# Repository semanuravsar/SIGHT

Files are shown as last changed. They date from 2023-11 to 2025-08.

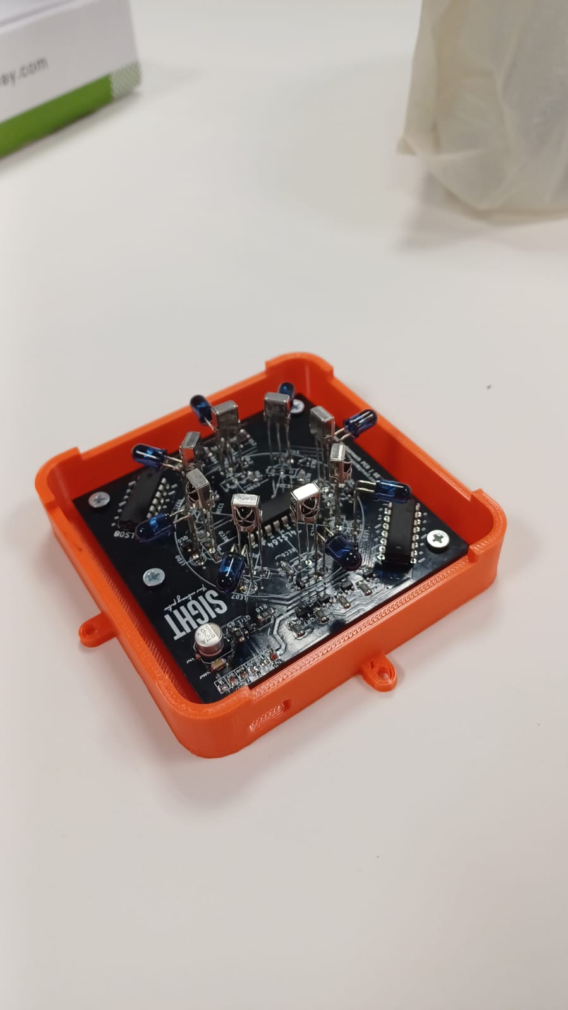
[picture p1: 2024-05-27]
Final Demo Poster/images/com_case_1.jpeg

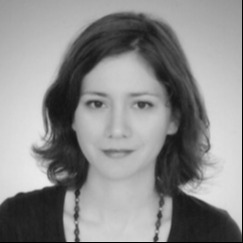
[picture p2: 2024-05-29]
Final Demo Poster/images/elif_photo-modified.jpg

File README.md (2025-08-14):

# SIGHT
A repository for the Ad-Hoc Comm. Project of SIGHT company.

## **Overview**  
This project implements an **autonomous multi-unit robotic system** for searching a **9×9 tiled field** to locate a designated target.  

- Each tile has an **RFID tag** encoding its coordinates and whether it contains the target.  
- The system includes multiple **Mobile Units (MUs)** and one **Base Unit (BU)**.  
- **MUs**: Search assigned regions, detect targets, share findings **with each other** via narrow-angle communication links, and converge when a target is found.  
- **BU**: Broadcasts target location to all units once detected.  

**Search Strategy – Predetermined Area Assignment**  
- The field is divided into three **3×9 regions**, one per MU.  
- Units scan their assigned regions independently.  
- Upon detecting the target, the discovering MU shares its location, prompting all units to converge.  

## **Video Demonstration**  
Watch the project in action here:  
- [Project Video](https://www.youtube.com/watch?v=MVDLl5eAIYU)  

## Poster
- [Project Poster (PDF)](Final%20Demo%20Poster/Sight_poster_30_05_2024_05-17.pdf)

## Final Report
- [Project Final Report (PDF)](reports/Final-Report.pdf)

---

## **Subsystems**  

### **1. Communication Unit**  
- **Hardware:** 8 × IR transmitter/receiver pairs at 45° spacing.  
- **Operation:** Sequentially activates pairs to determine direction of incoming pings.  
- **Communication Type:** **Narrow-angle IR**, enabling targeted, directional data exchange between MUs and reducing interference.  
- **Protocol:**  
  - Custom **ping/ack** messages: 3-byte payload + 1-byte CRC.  
  - Payload includes: next position, unit ID, search state, target position.  
  - CRC ensures data integrity.  
- **Search States:** 6 defined (moving to area, searching, target not found, target found, moving to target, target reached). Ack = state + 9.  
- **Performance:** ≥95% success within ±22.5° at 0.5 m; ≥90% at 1 m; stable for 4-, 8-, and 12-byte packets at 1 m.  

### **2. Decision Unit**  
- Implements the **Predetermined Area Assignment** algorithm.  
- Maintains latest states/positions of other MUs to prevent collisions.  
- Assigns movement priorities based on defined search states.  

### **3. Sensing Unit**  
- **Method:** RFID-based localization.  
- **Hardware:**  
  - Passive **13.56 MHz RFID tags** on each tile.  
  - Target tiles: coordinate values incremented by +9.  
  - Each MU has an RFID reader mounted underneath.  
- **Operation:**  
  - Reads tags in milliseconds while moving at 10 cm/s (no stop needed).  
  - On read, MU pauses 500 ms to process.  

### **4. Motion Unit**  
- **Submodules:** Mechanical, driving, and feedback.  
- **Driving:**  
  - **L293N H-bridge** motor driver.  
  - Direction via IN pins, speed via PWM on EN pins.  
  - Gradual PWM ramp to avoid surges and resets.  
- **Feedback & Navigation:**  
  - Line follower on black-on-white grid.  
  - Ensures accurate RFID positioning.  
- **Recovery:** Back-and-forth routine if tag read is missed.  

### **5. Power Unit**  
- **Consumption:** ~4.6 W average (motors ~3.45 W).  
- **Supply:** Two 18650 Li-ion cells in series (7.4 V, 3.5 A peak).  
- **Runtime:** >5 hours at worst-case 7.5 W.  
- **Regulation:** Linear 5 V; remove batteries for charging.  

## **System Workflow**  
1. MUs start at the base and move toward their assigned regions.  
2. Each MU scans tiles, reading RFID tags to determine position and target status.  
3. MUs exchange status and target information with each other via **narrow-angle IR communication**.  
4. If a target is detected, the discovering MU broadcasts location, and all MUs converge on it.  

---

## Authors
Erdem Canaz, Semanur Avşar, Humeyra Bodur, Özge Deniz Ateş, Berfin Kökmen, Yiğit Sayar

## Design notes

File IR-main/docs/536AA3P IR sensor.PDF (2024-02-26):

Part Number : 536AA3P, TSOP1136, TSOP1736

Manufacturers : Vishay

Function : IR Receiver Module

Image :

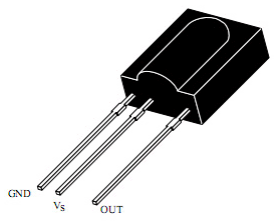
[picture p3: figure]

Description
The 536AA3P is miniaturized receivers for infrared remote control systems. A PIN diode and a preamplifier are assembled on a lead frame, the epoxy package acts as an IR filter.

Features

### 1. Very low supply current 2. Photo detector and preamplifier in one package 3. Internal filter for PCM frequency 4. Improved shielding against EMI

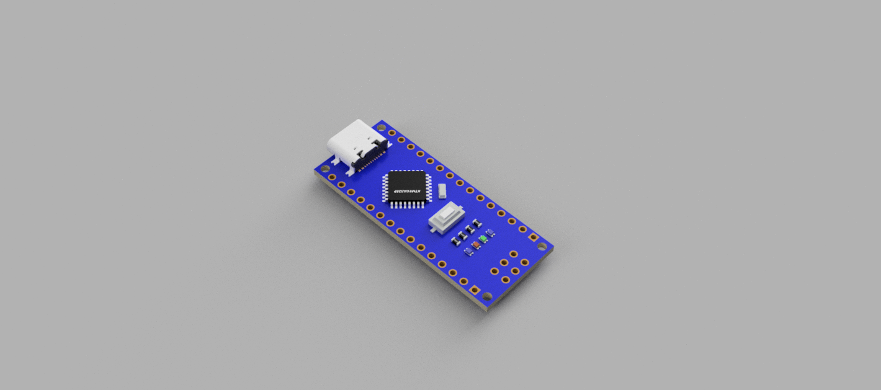
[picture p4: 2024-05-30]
Final Demo Poster/images/Arduino Nano Alibaba v1.png

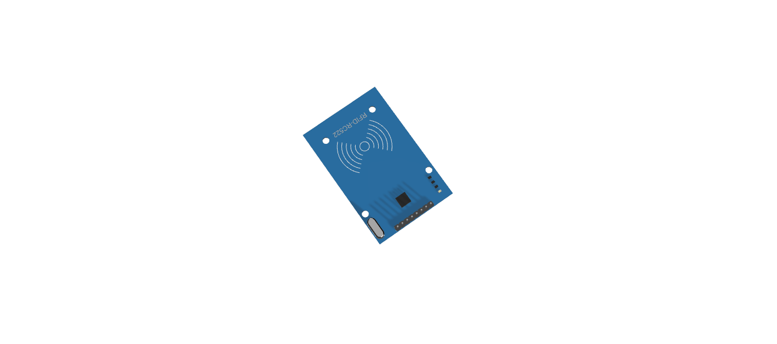
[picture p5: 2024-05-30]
Final Demo Poster/images/RFID.png

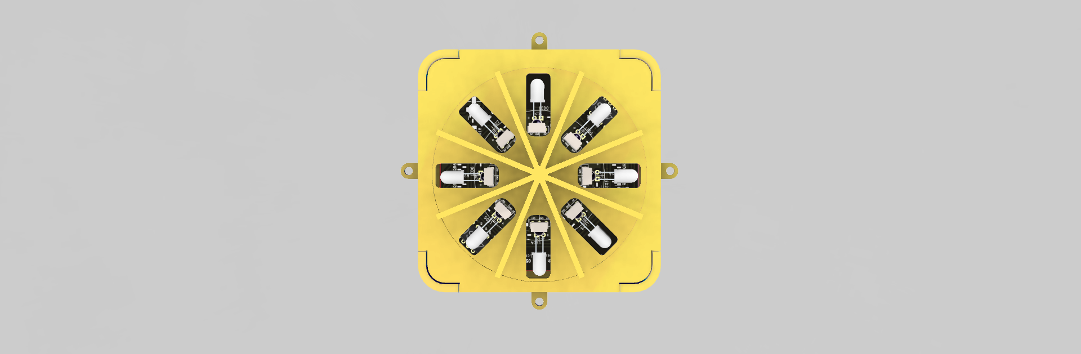
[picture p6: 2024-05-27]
Final Demo Poster/images/com_3D_top.png

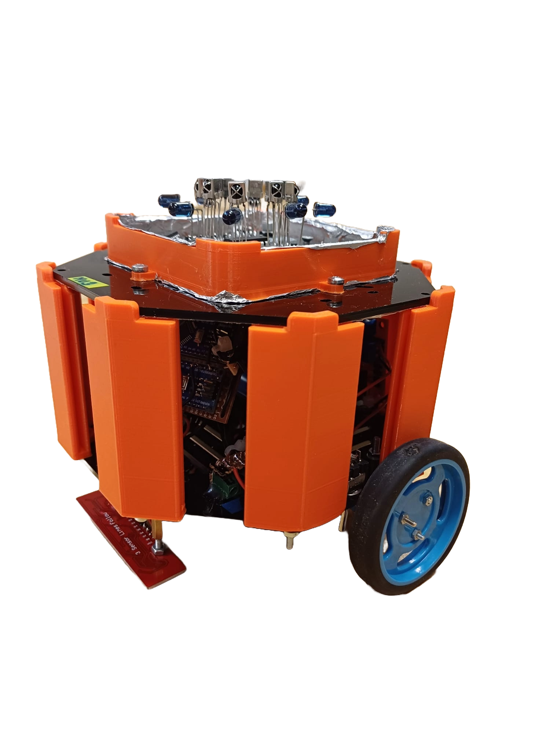
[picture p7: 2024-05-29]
Final Demo Poster/images/mu_nobg.png

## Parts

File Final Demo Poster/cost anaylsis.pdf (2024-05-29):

Microcontrollers | $40
Motor drivers, motors and wheels | $36
Batteries | $26.5
Line follower and RFID reader sensors | $12
RFID Tags | $14.5
IR transmitters, receivers and PCB | $36
Chassis | $10
Grid | $66
Circuit components (Breadboard, cables, resistors) | $10
Total Cost | $251

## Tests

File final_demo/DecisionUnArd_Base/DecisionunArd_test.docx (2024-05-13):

// The values info matrix represent the following;

// mu1 is here == 1

// mu2 is here == 2

// mu3 is here == 3

// BU is here == 4

// This tile is scanned == 5

// This tile has not been scanned == 0

// The target is there == 6

// mu is planning to go here == 7

// obtacle here == 8

#include "DecisionUnArd_header.h";

// Define positions

Position buPosition = {5, 5};

Position currentPosition = {6, 1};

// Position unknownTargetPosition = {1, 9};

Position targetPosition = {7,9};

// Define obstacles

Position obstacles[MAX_OBSTACLES];

int obstacleCount = 2;

int buLink = 0;

// Define mu_info_matrix

int mu_info_matrix[GRID_SIZE][GRID_SIZE] = {

{0, 0, 0, 0, 0, 0, 0, 0, 0},

{0, 0, 0, 0, 8, 8, 0, 0, 0},

{0, 0, 0, 0, 0, 0, 0, 0, 0},

{7, 7, 7, 7, 7, 7, 7, 7, 7},

{7, 7, 7, 7, 4, 7, 7, 7, 7},

{7, 7, 7, 7, 7, 7, 7, 7, 7},

{7, 7, 7, 7, 7, 7, 7, 7, 7},

{7, 7, 7, 7, 7, 7, 7, 7, 7},

{7, 7, 7, 7, 7, 7, 7, 7, 7}

};

// Set state to MOVING_TO_SEARCH_AREA

int state = MOVING_TO_SEARCH_AREA;

// Test function

// Test function

void test_move_decider_MU1() {

// Call move_decider_MU1

Position nextMoveResult = move_decider_MU1(buPosition, currentPosition, targetPosition, obstacles, obstacleCount, mu_info_matrix, state, buLink);

if(nextMoveResult.x != 0 || nextMoveResult.y != 0){

// Checking first the BU connecition

if(((buPosition.x-currentPosition.x)^2 + (buPosition.y-currentPosition.y)^2)<10){

buLink = 1;

Serial.println("**************BU LINK IS ESTABLISHED");

}

else{

buLink = 0;

Serial.println("**************NO LINK WITH THE BU");

}

// Updating the info matrix

if(currentPosition.x == targetPosition.x && currentPosition.y == targetPosition.y){

Serial.println("Target has been found.");

state = TARGET_FOUND;

// Updating the info matrix

mu_info_matrix[currentPosition.x-1][currentPosition.y - 1] = 6;

}

else{

mu_info_matrix[currentPosition.x-1][currentPosition.y - 1] = 5;

}

currentPosition.x = currentPosition.x + nextMoveResult.x;

currentPosition.y = currentPosition.y + nextMoveResult.y;

mu_info_matrix[currentPosition.x-1][currentPosition.y - 1] = 1;

// If our state is searching and we have not more unscaenned tiles left

if(state == CURRENTLY_SEARCHING && !unscannedTileLeft(mu_info_matrix)){

state = TARGET_NOT_FOUND;

}

}

// Output the result

Serial.print("Move made: (");

Serial.print(nextMoveResult.x);

Serial.print(", ");

Serial.print(nextMoveResult.y);

Serial.println(")");

// Current State

Serial.print("Current State: ");

Serial.println(state);

// Current Position

// Output the result

Serial.print("Current Position: (");

Serial.print(currentPosition.x);

Serial.print(", ");

Serial.print(currentPosition.y);

Serial.println(")");

// Print out the mu_info_matrix

Serial.println("mu_info_matrix:");

for (int i = 0; i < GRID_SIZE; i++) {

for (int j = 0; j < GRID_SIZE; j++) {

Serial.print(mu_info_matrix[i][j]);

Serial.print("\t");

}

Serial.println();

}

}

// Setup function

void setup() {

// Initialize serial communication

Serial.begin(9600);

obstacles[0].x = 2;

obstacles[0].y = 5;

obstacles[1].x = 2;

obstacles[1].y = 6;

// Test the move_decider_MU1 function

test_move_decider_MU1();

test_move_decider_MU1();

test_move_decider_MU1();

test_move_decider_MU1();

test_move_decider_MU1();

test_move_decider_MU1();

test_move_decider_MU1();

test_move_decider_MU1();

test_move_decider_MU1();

test_move_decider_MU1();

test_move_decider_MU1();

test_move_decider_MU1();

test_move_decider_MU1();

test_move_decider_MU1();

test_move_decider_MU1();

test_move_decider_MU1();

test_move_decider_MU1();

test_move_decider_MU1();

test_move_decider_MU1();

test_move_decider_MU1();

test_move_decider_MU1();

test_move_decider_MU1();

test_move_decider_MU1();

test_move_decider_MU1();

test_move_decider_MU1();

test_move_decider_MU1();

test_move_decider_MU1();

test_move_decider_MU1();

test_move_decider_MU1();

test_move_decider_MU1();

test_move_decider_MU1();

test_move_decider_MU1();

test_move_decider_MU1();

test_move_decider_MU1();

test_move_decider_MU1();

test_move_decider_MU1();

test_move_decider_MU1();

// Gets in the perimiter of the BU

test_move_decider_MU1();

test_move_decider_MU1();

test_move_decider_MU1();

test_move_decider_MU1();

Serial.println(buLink);

test_move_decider_MU1();

test_move_decider_MU1();

test_move_decider_MU1();

// Receives the info on the target from another MU

state = MOVING_TO_TARGET;

test_move_decider_MU1();

test_move_decider_MU1();

test_move_decider_MU1();

test_move_decider_MU1();

test_move_decider_MU1();

test_move_decider_MU1();

test_move_decider_MU1();

test_move_decider_MU1();

test_move_decider_MU1();

test_move_decider_MU1();

}

// Loop function

void loop() {

// Nothing to do here since we're testing in setup()

}

// Function to check if all elements in the matrix are non-zero

bool unscannedTileLeft(const int matrix[GRID_SIZE][GRID_SIZE]) {

for (int i = 0; i < GRID_SIZE; i++) {

for (int j = 0; j < GRID_SIZE; j++) {

if (matrix[i][j] == 0) {

return true;

}

}

}

return false;

}

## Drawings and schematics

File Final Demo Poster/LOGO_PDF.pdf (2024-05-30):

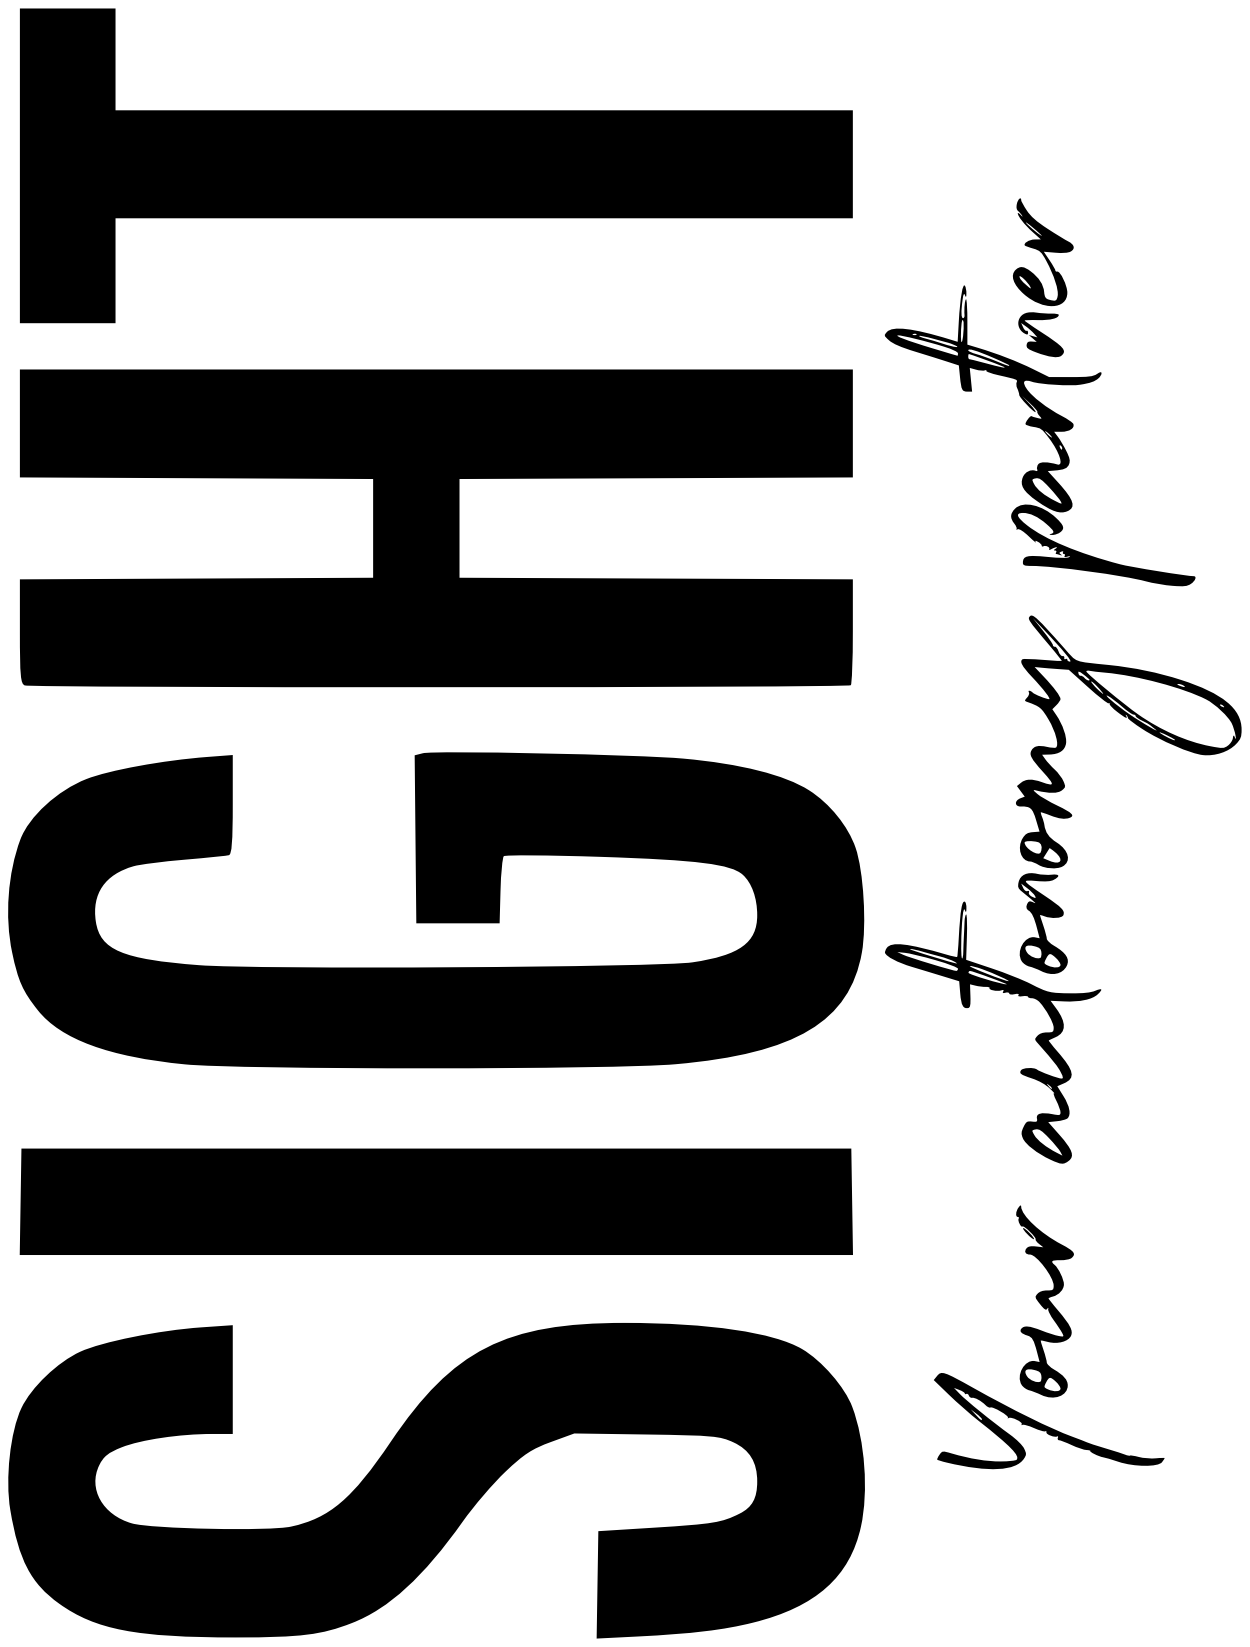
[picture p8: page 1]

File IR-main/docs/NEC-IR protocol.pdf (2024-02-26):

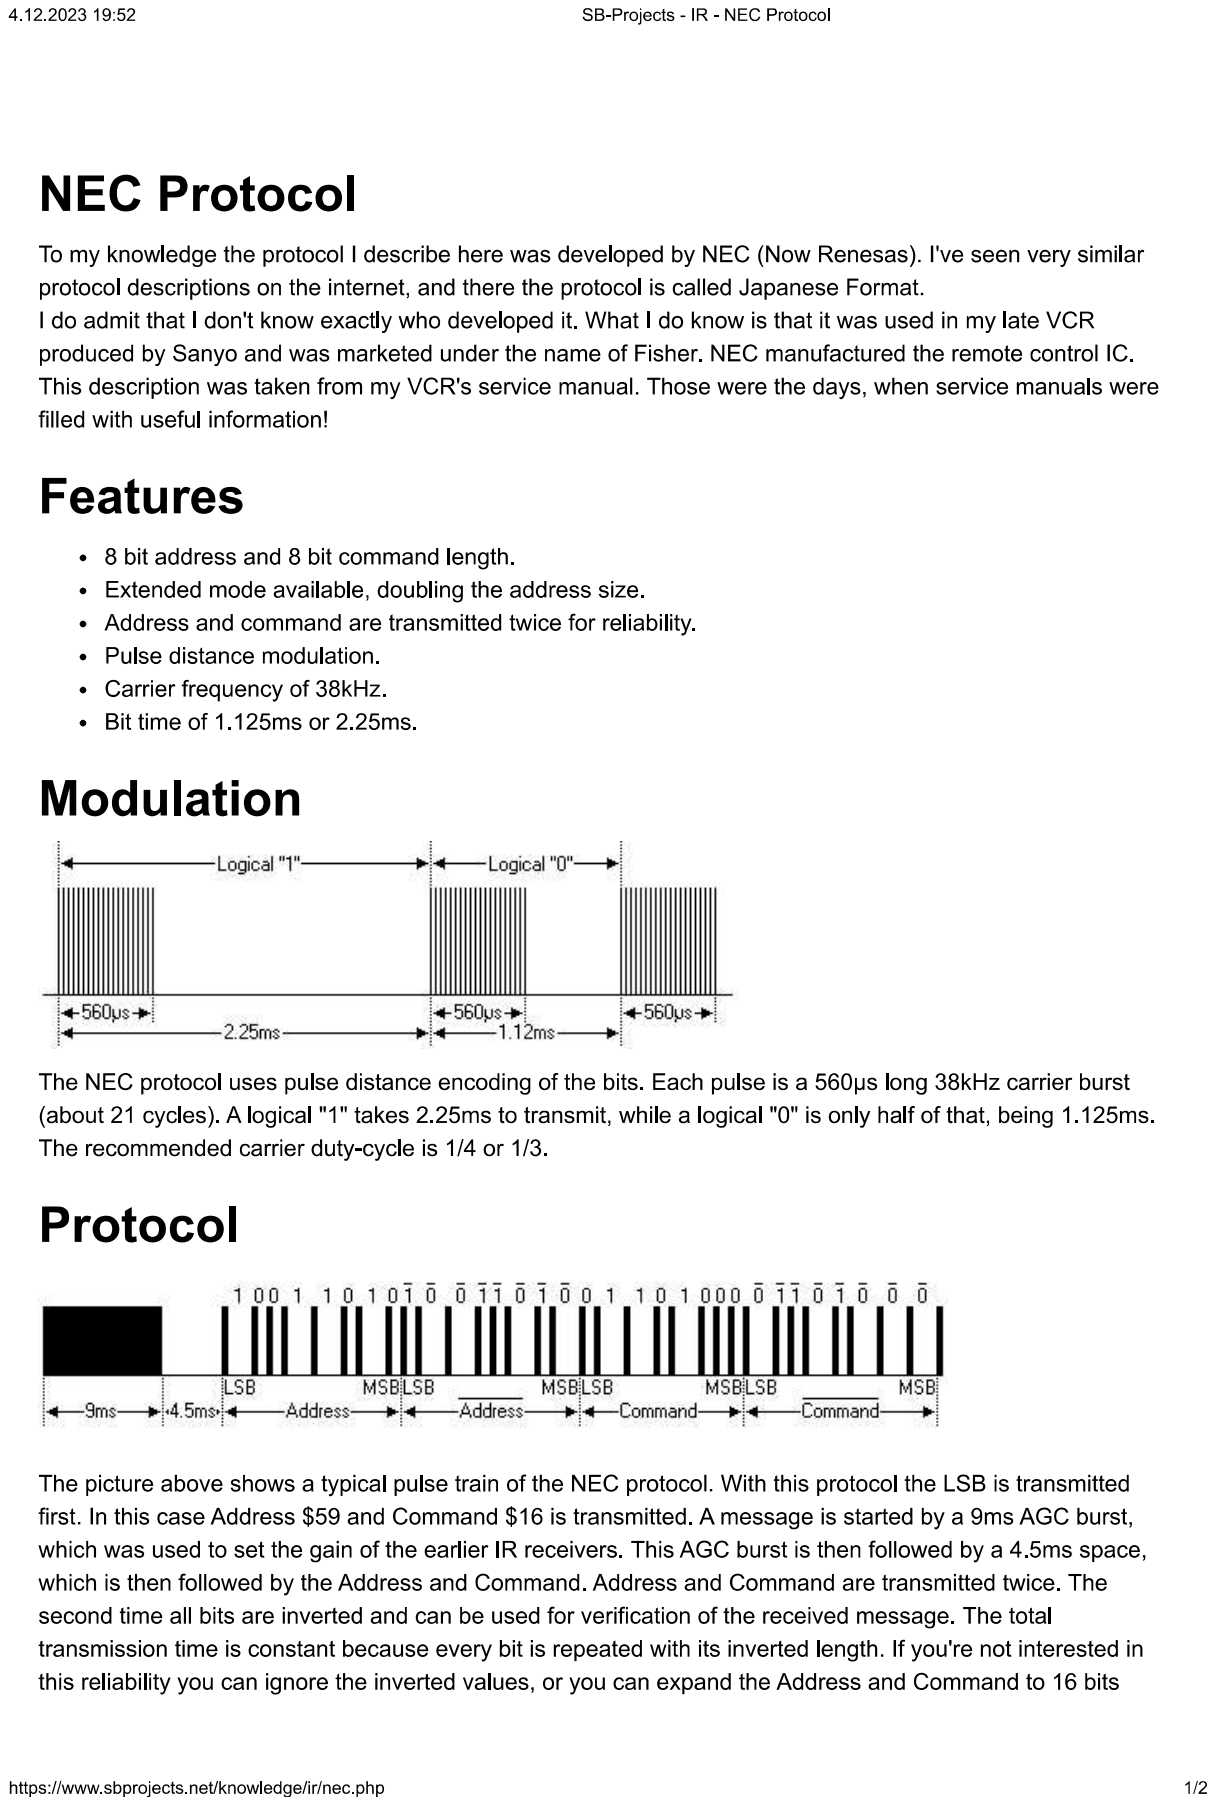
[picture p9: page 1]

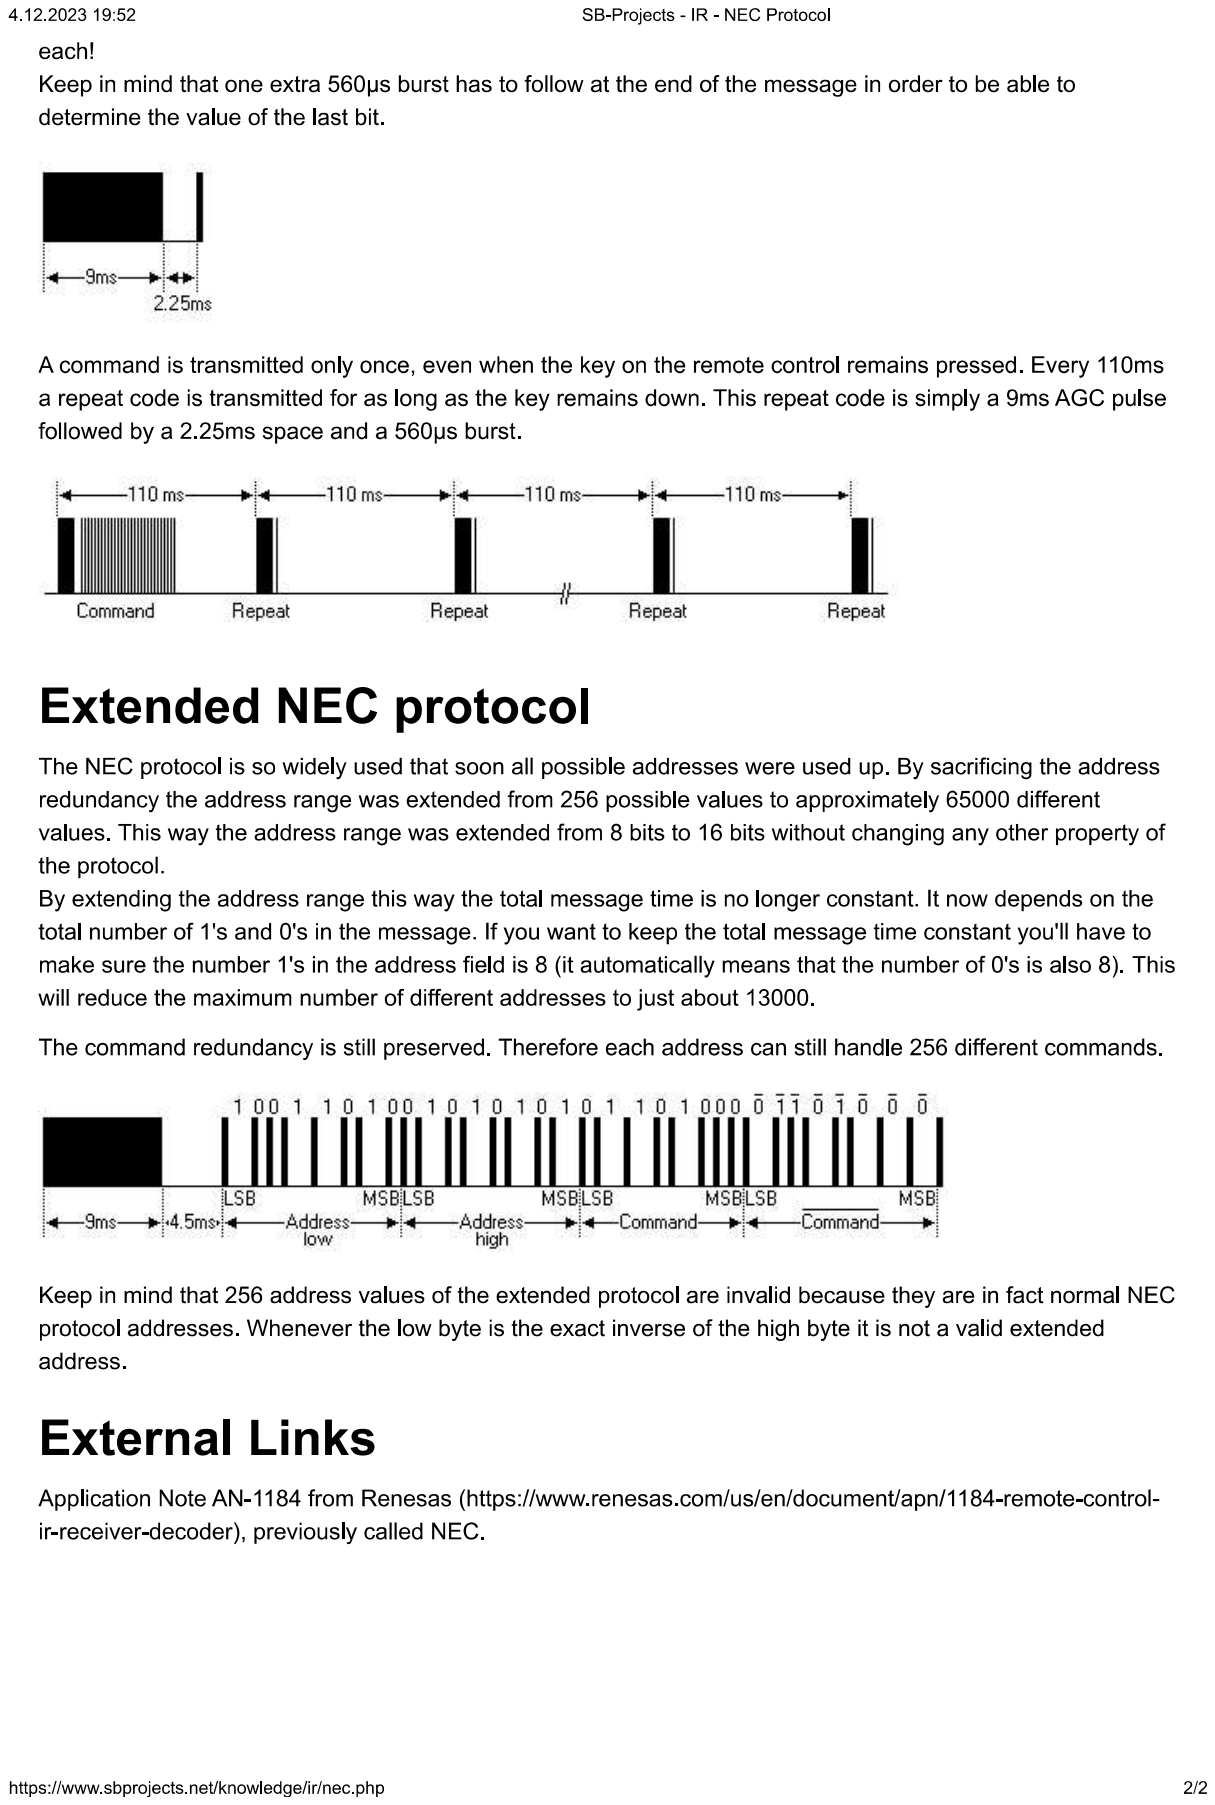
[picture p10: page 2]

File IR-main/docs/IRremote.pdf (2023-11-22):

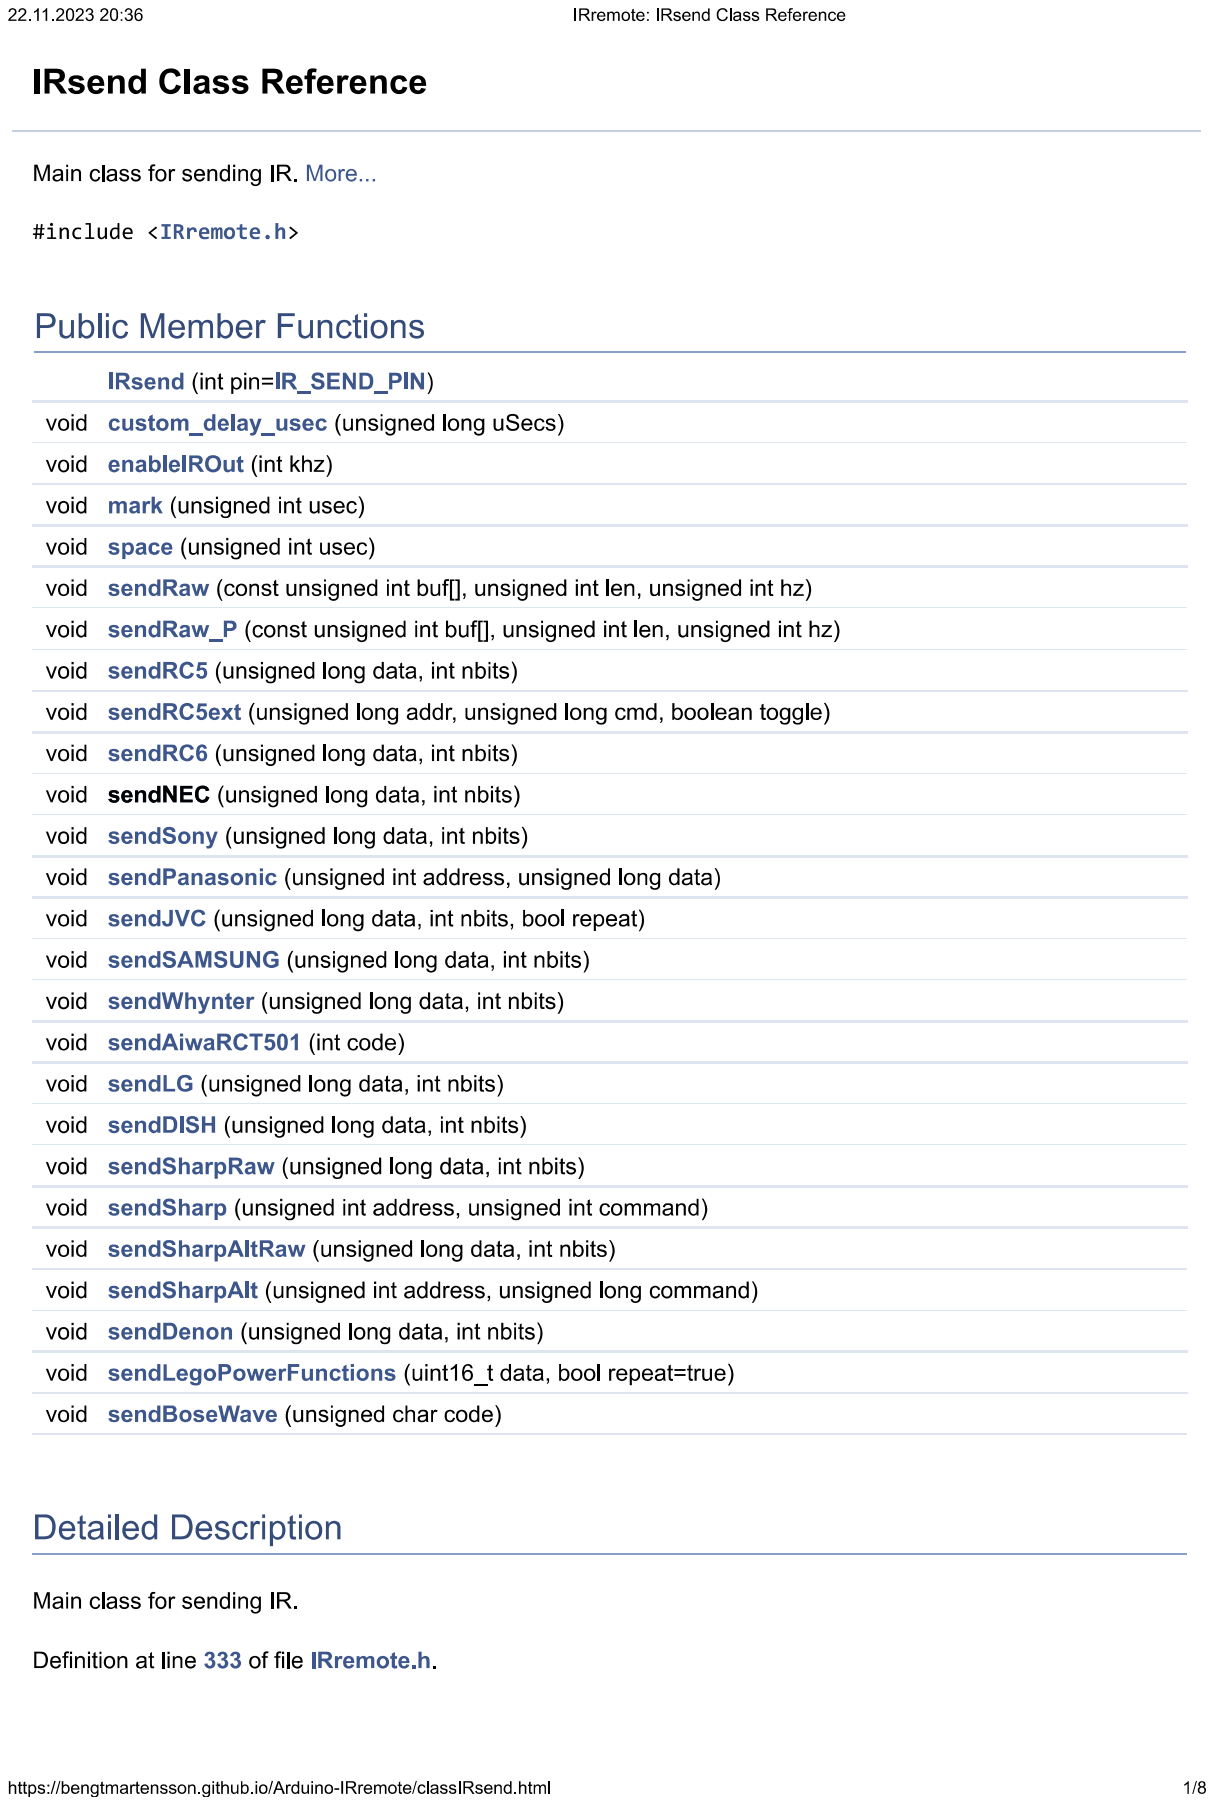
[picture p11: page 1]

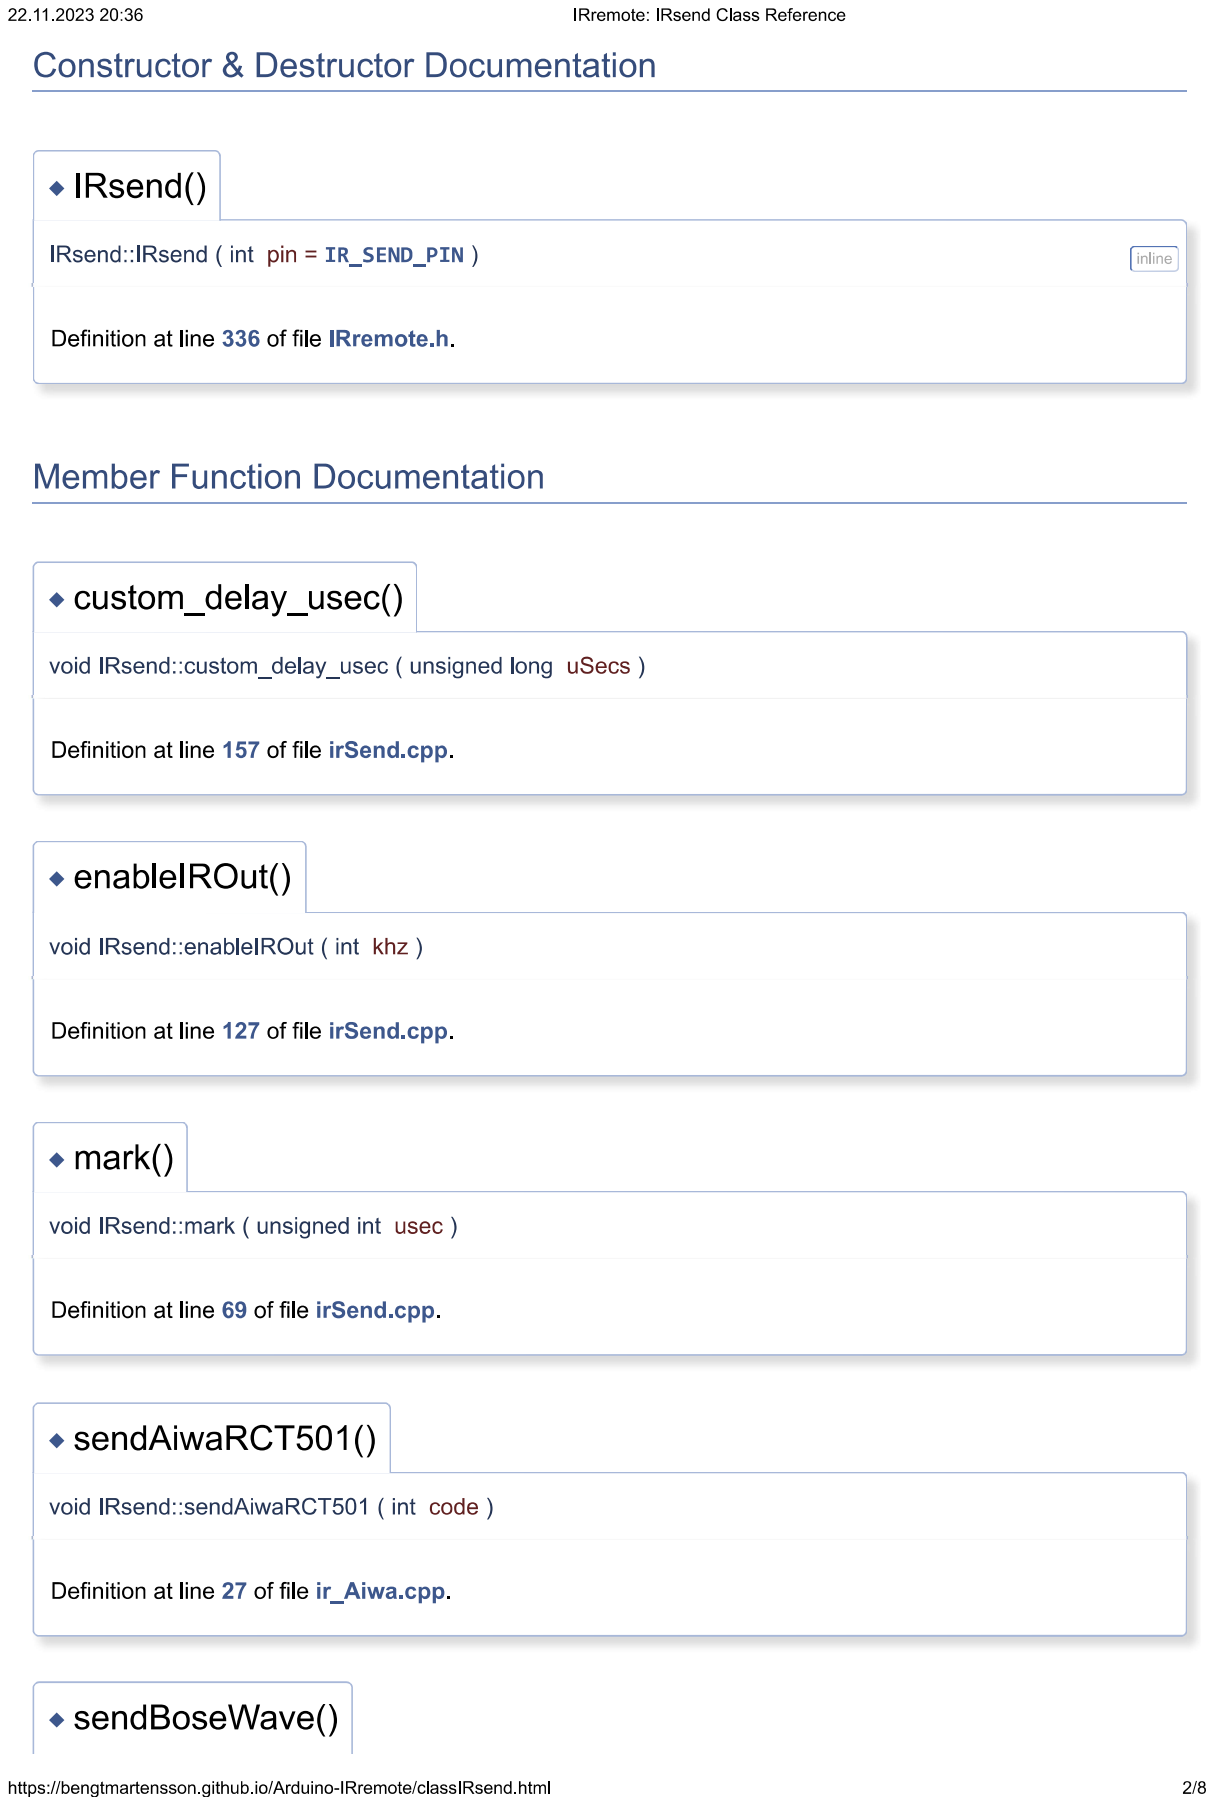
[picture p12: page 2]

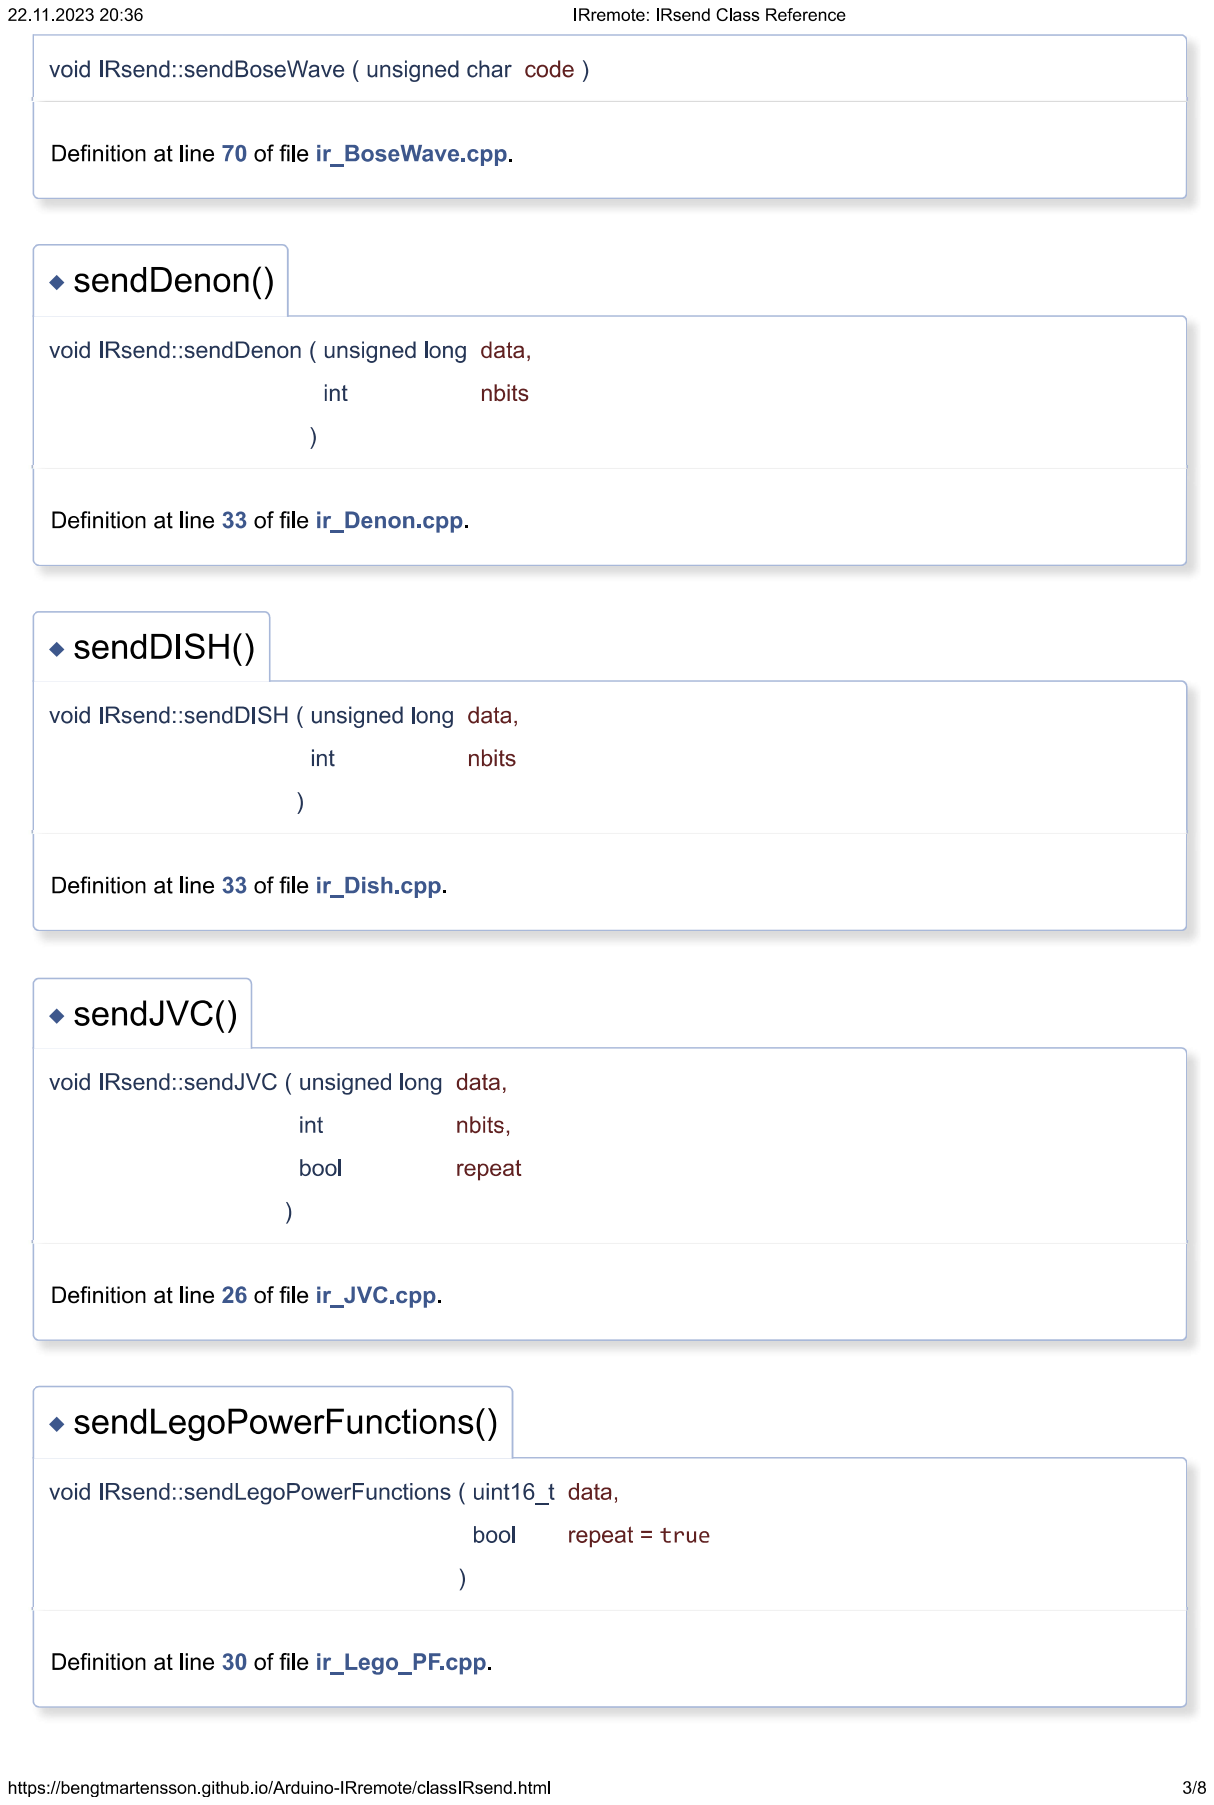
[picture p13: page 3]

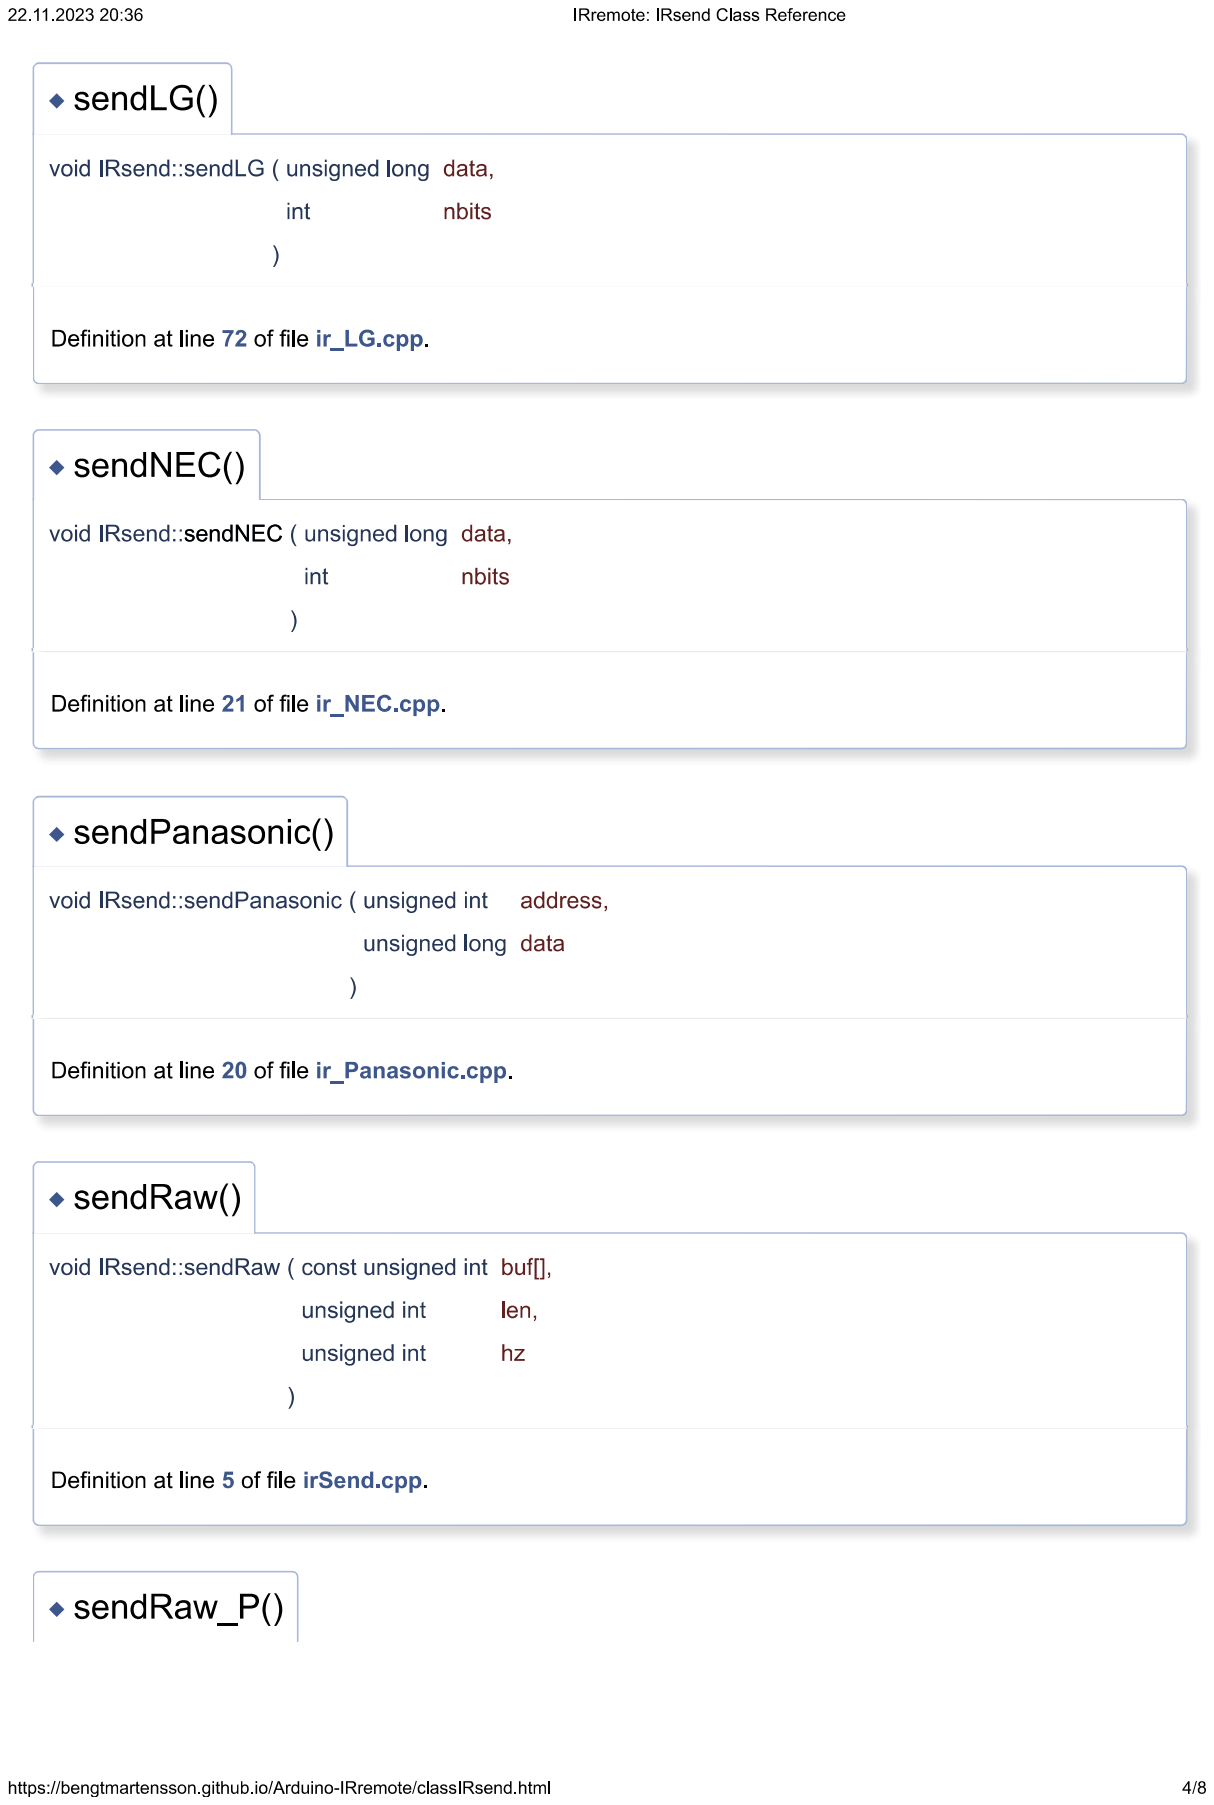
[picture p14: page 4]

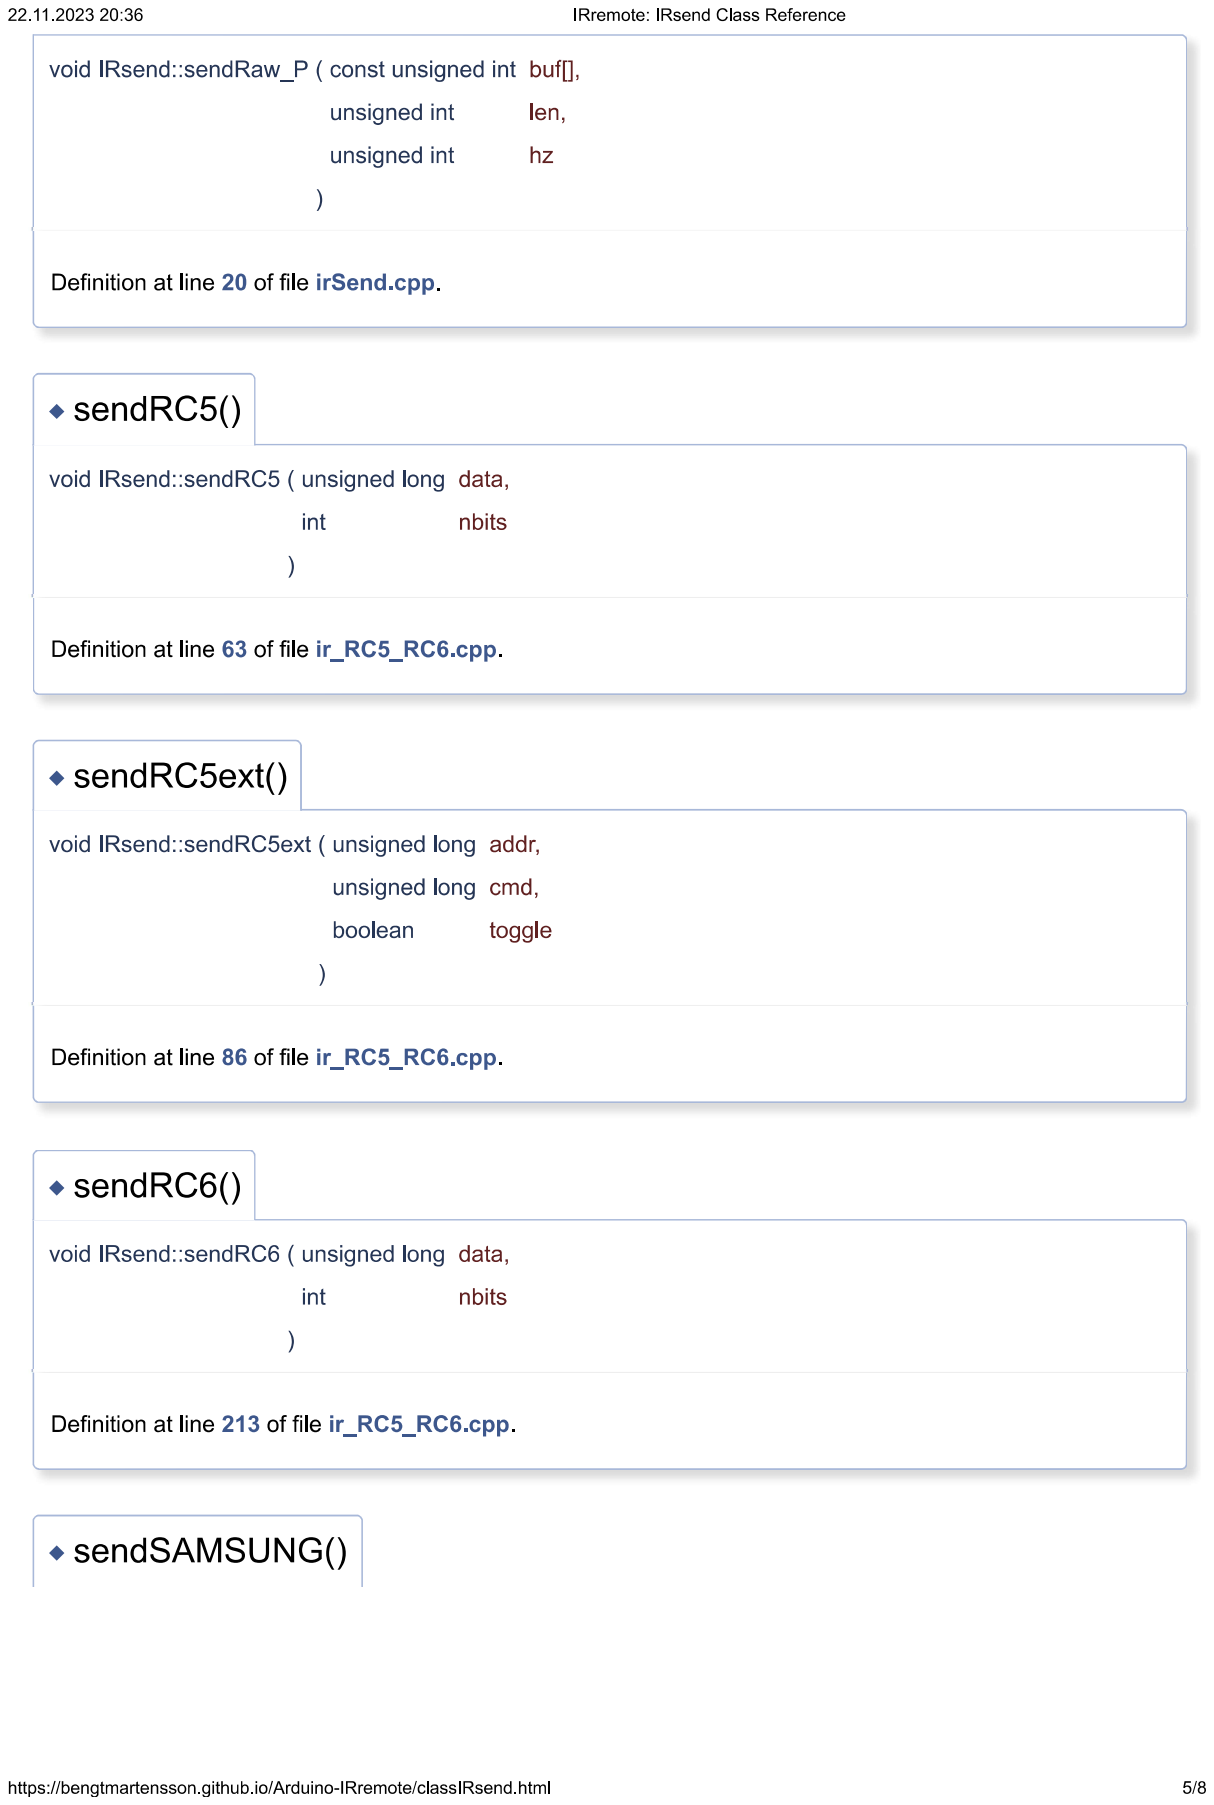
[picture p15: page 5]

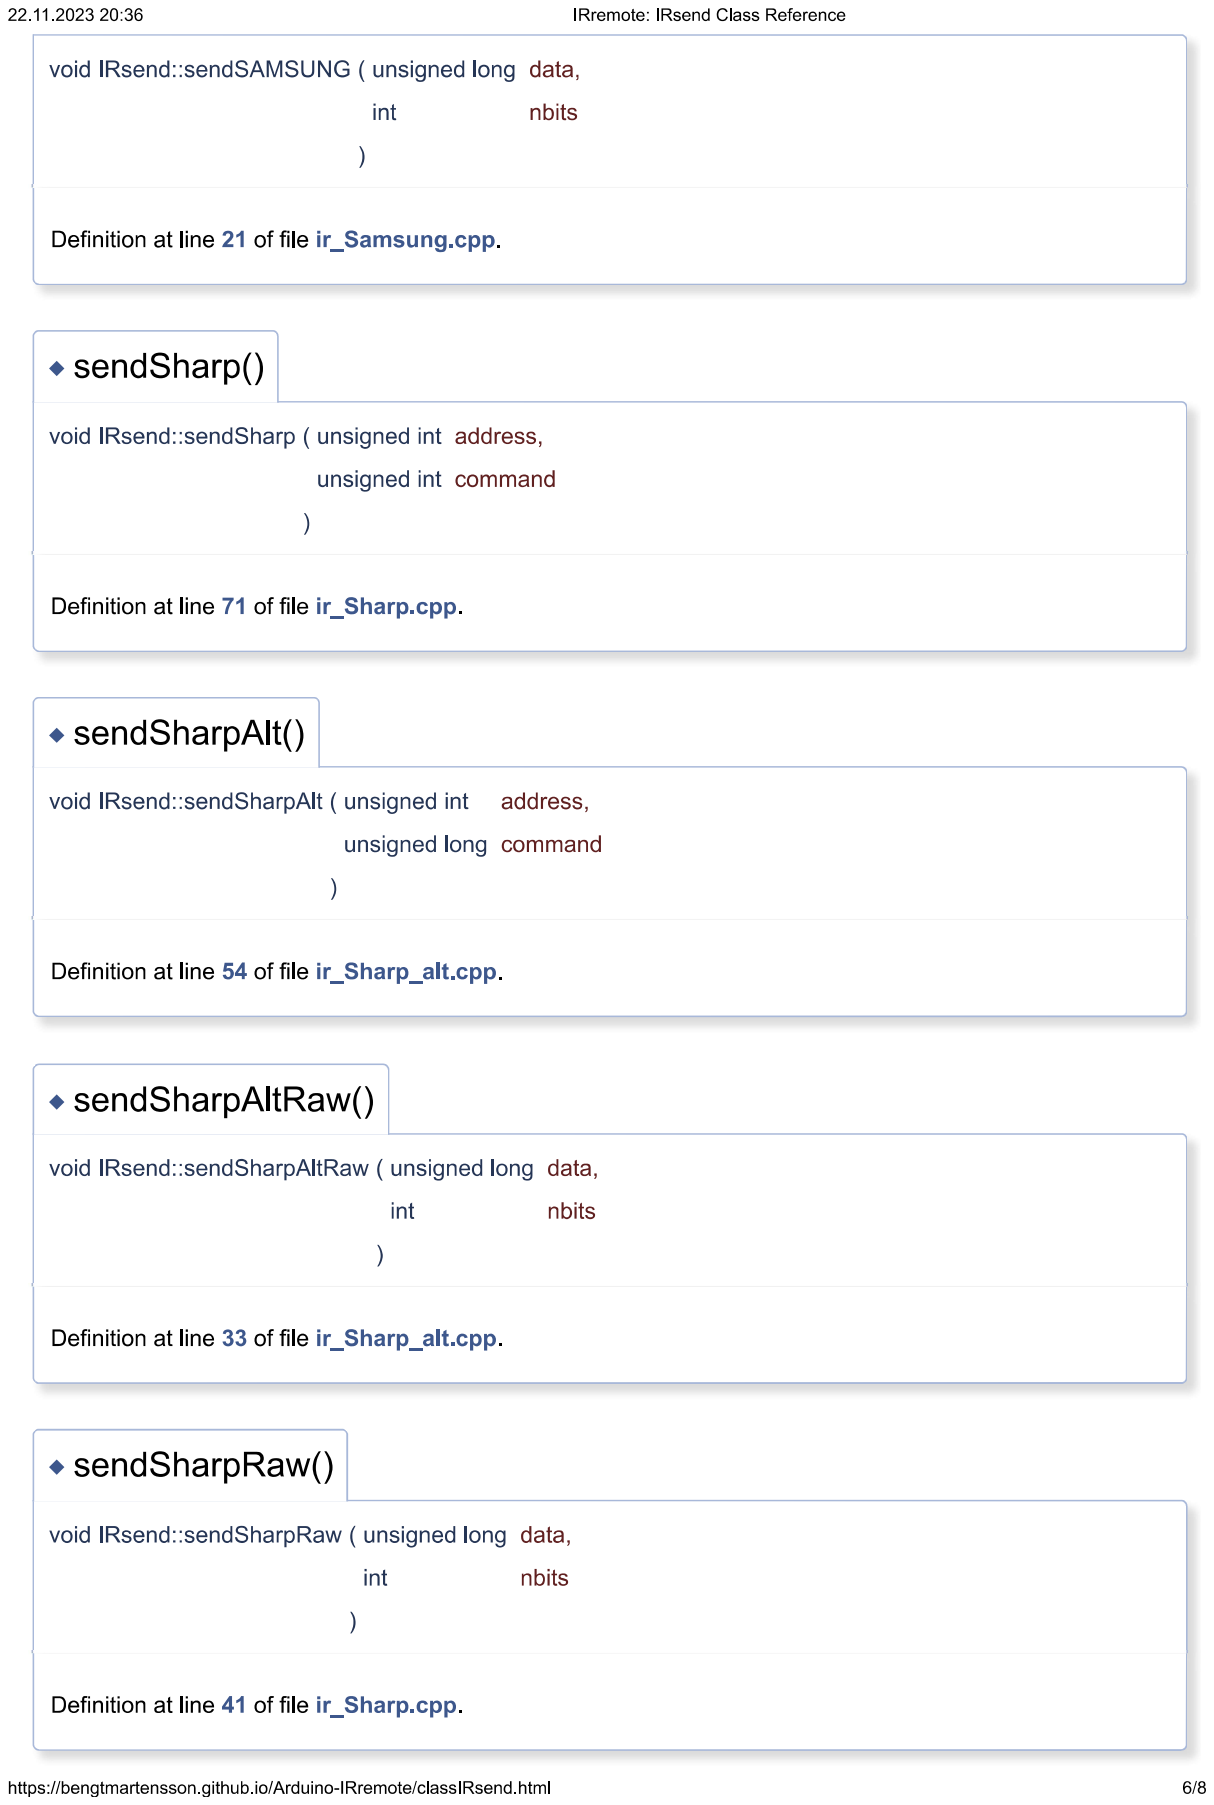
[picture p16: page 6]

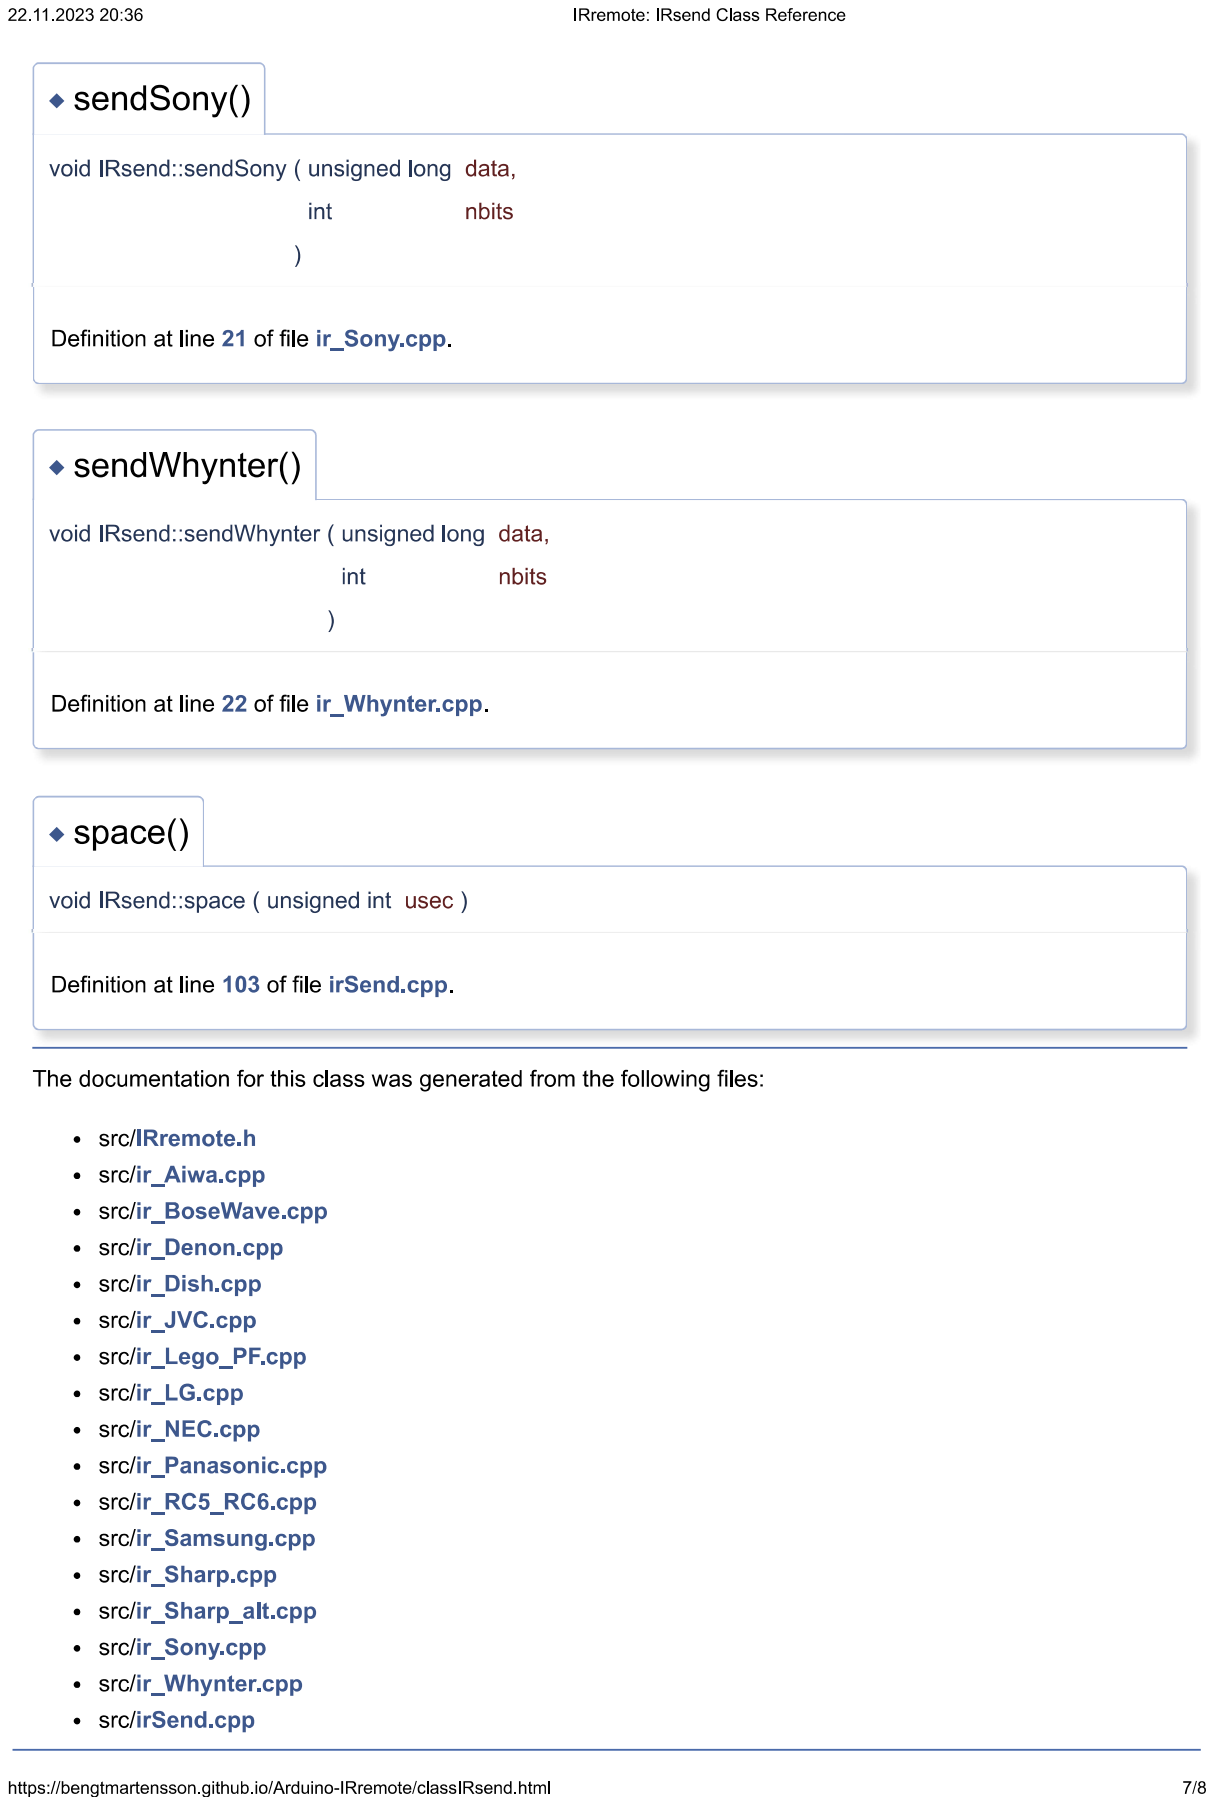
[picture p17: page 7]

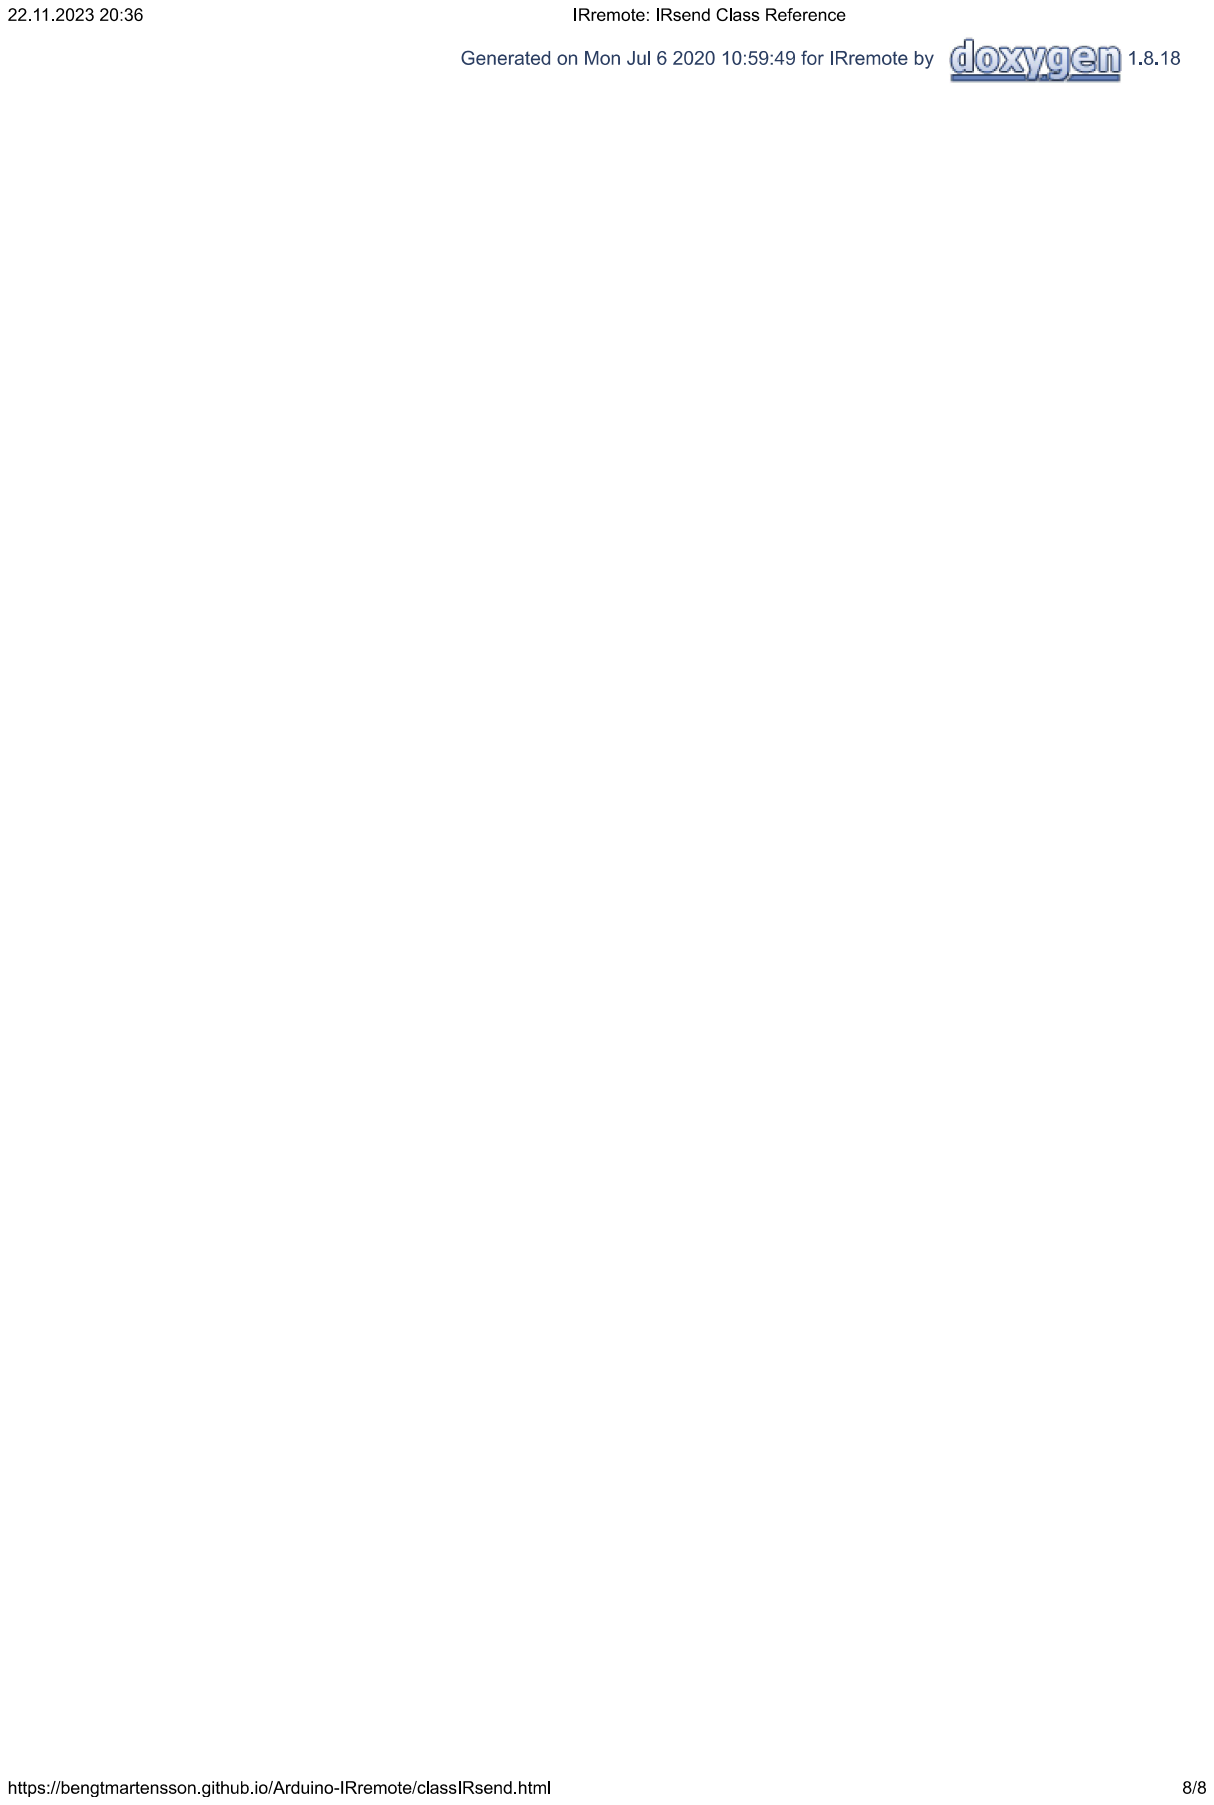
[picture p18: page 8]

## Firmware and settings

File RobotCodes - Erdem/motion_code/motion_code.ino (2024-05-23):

#define BATTERY_VOLTAGE 7.4  //in volts

#define BLACK_THRESHOLD 850  //if analogRead() value is greater than this, black is detected

#define WHEEL_RADIUS 0.03        //in meters
#define MOTOR_RATED_RPM 60       // turns per minute
#define MOTOR_RATED_VOLTAGE 6.0  //rated voltage of the motor
#define MOTOR1_PWM 3
#define MOTOR1_A 5
#define MOTOR1_B 4
#define MOTOR2_PWM 11
#define MOTOR2_A 9
#define MOTOR2_B 10

//#define LED_PIN 13
#define ISRESETTED 13
#define RFID_READ 2  // aka TALK_PIN
#define FOLLOWING_THE_LINE 1
#define AT_CROSS_SECTION 2


unsigned int threshold = 750;  // Threshold for detecting black
uint8_t indicator = 0;
uint8_t oldData = 0;
uint16_t turn_delay = 1000;
unsigned long oldData_startTime = 0;
int buzzerPin = 8;
int movement_terminated = 0;

uint8_t line_follower_analog_pins[8] = { A0, A1, A2, A3, A4, A5, A6, A7 };  // A0-> 1 (left) A7->8 (right)Define the analog input pins

void setup() {
  // Pins D3 and D11 - 8 kHz
  TCCR2B = 0b00000010;  // x8
  TCCR2A = 0b00000011;  // fast pwm

  delay(2500);
  Serial.begin(9600);
  for (uint8_t i = 0; i < 8; i++) {
    pinMode(line_follower_analog_pins[i], INPUT);
  }
  pinMode(ISRESETTED, OUTPUT);
  digitalWrite(ISRESETTED, HIGH);
  delay(2000);
  digitalWrite(ISRESETTED, LOW);
  // pinMode(LED_PIN, OUTPUT);
  pinMode(MOTOR1_PWM, OUTPUT);
  pinMode(MOTOR1_A, OUTPUT);
  pinMode(MOTOR1_B, OUTPUT);

  pinMode(MOTOR2_PWM, OUTPUT);
  pinMode(MOTOR2_A, OUTPUT);
  pinMode(MOTOR2_B, OUTPUT);
  pinMode(RFID_READ, INPUT);
  pinMode(buzzerPin, OUTPUT);
}

void loop() {
  if (movement_terminated == 1) {
    set_motor_speeds(0, 0);
    while (true) {  // MU is halted!!
      digitalWrite(buzzerPin, HIGH);
      delay(50);
      digitalWrite(buzzerPin, LOW);
      delay(950);
    }
  }

  move_forward_until_line_crossing(5000);
  delay(500);
  int decision_unit_command = move_forward_until_RFID_read_serial();
  delay(1000);

humeyra_yuzunden_bu_goto:
  if (decision_unit_command == 0) {
    set_motor_speeds(0, 0);
  } else if (decision_unit_command == 1) {
    // open_loop_go_forward(0.23);
    // GOES FORWARD
  } else if (decision_unit_command == 2) {
    // open_loop_turn_right(74.0);
    turn_right_closed_loop();
  } else if (decision_unit_command == 3) {
    // open_loop_turn_left(74.0);
    turn_left_closed_loop();
  } else if (decision_unit_command == 4) {
    // open_loop_turn_right(140.0);
    turn_right_closed_loop();
    turn_right_closed_loop();
  } else if (decision_unit_command == 5) {
    movement_terminated = 1;
    set_motor_speeds(0, 0);
  }
  // STOP FOR BU COMM AND THEN GO FORWARD
  else if (decision_unit_command == 6) {
    set_motor_speeds(0, 0);
    delay(5000);
    // open_loop_go_forward(0.23);
  }
  // STOP FOR BU COMM AND THEN TURN RIGHT
  else if (decision_unit_command == 7) {
    set_motor_speeds(0, 0);
    delay(5000);
    // open_loop_turn_right(74.0);
    turn_right_closed_loop();
  }
  // STOP FOR BU COMM AND THEN TURN LEFT
  else if (decision_unit_command == 8) {
    set_motor_speeds(0, 0);
    delay(5000);
    // open_loop_turn_left(74.0);
    turn_left_closed_loop();
  }
  // STOP FOR BU COMM AND THEN TURN AROUND
  else if (decision_unit_command == 9) {
    set_motor_speeds(0, 0);
    delay(5000);
    // open_loop_turn_right(140.0);
    turn_right_closed_loop();
    turn_right_closed_loop();
  } else if (decision_unit_command == 10) {
    set_motor_speeds(0, 0);
    while (true) {
      if (Serial.available() > 0) break;
    }
    decision_unit_command = Serial.read();
    goto humeyra_yuzunden_bu_goto;
  }
}

uint8_t is_black[8] = { 0, 0, 0, 0, 0, 0, 0, 0 };  // if i'th sensor is black, set to 1. otherwise 0

uint8_t update_black_detections() {
  for (uint8_t i = 0; i < 8; i++) {
    int analog_value = analogRead(line_follower_analog_pins[i]);
    uint8_t digital_val = 0;
    if (analog_value > BLACK_THRESHOLD) digital_val = 1;
    is_black[i] = digital_val;
  }
}

void test_print_is_black_array() {
  for (uint8_t i = 0; i < 8; i++) {
    Serial.print(String(is_black[i]) + " ");
  }
  Serial.println("");
}

void set_motor_speeds(float M1_speed, float M2_speed) {
  // M1 and M2 speeds are in meters per second and negative value means reverse direction.
  float max_speed = (BATTERY_VOLTAGE / MOTOR_RATED_VOLTAGE) * (MOTOR_RATED_RPM / 60.0) * (6.28 * WHEEL_RADIUS);  //in meters per second, 0.23m/s for recent motor.

  //set the direction
  if (M1_speed > 0) {
    digitalWrite(MOTOR1_A, LOW);
    digitalWrite(MOTOR1_B, HIGH);
  } else {
    digitalWrite(MOTOR1_A, HIGH);
    digitalWrite(MOTOR1_B, LOW);
  }

  if (M2_speed > 0) {
    digitalWrite(MOTOR2_A, HIGH);
    digitalWrite(MOTOR2_B, LOW);
  } else {
    digitalWrite(MOTOR2_A, LOW);
    digitalWrite(MOTOR2_B, HIGH);
  }

  //consider the magnitudes of the speeds since the directions are set.
  M1_speed = abs(M1_speed);
  M2_speed = abs(M2_speed);
  if (M1_speed > max_speed) M1_speed = max_speed;
  if (M2_speed > max_speed) M2_speed = max_speed;

  uint16_t M1_pwm = uint8_t(255.0 * (M1_speed / max_speed));
  uint16_t M2_pwm = uint8_t(255.0 * (M2_speed / max_speed));
  //Serial.println(String(M1_speed) + " " + String(M1_pwm) + " " + String(M2_speed) + " " + String(M2_pwm));

  analogWrite(MOTOR1_PWM, M1_pwm);
  analogWrite(MOTOR2_PWM, M2_pwm);
}

void open_loop_turn_right(float angle) {
  //it is found emprically that with below configuration, robot complates 10 complete turns in 40.87 seconds -> 4.87 seconds per 360 degree -> 0.0135 seconds per 1 degree.
  //By using this function, you can turn the robot in both left or right directions. Just insert negative angle to perform left turn.

  if (angle > 360) angle = 360;
  else if (angle < -360) angle = -360;

  uint16_t delay_duration = uint16_t(abs(angle) * 13.5);

  if (angle > 0) {
    set_motor_speeds(0.20, -0.20);
  } else {
    set_motor_speeds(-0.20, 0.20);
  }

  delay(delay_duration);
  set_motor_speeds(0, 0);
}

void open_loop_turn_left(float angle) {
  if (angle > 360) angle = 360;
  else if (angle < -360) angle = -360;

  uint16_t delay_duration = uint16_t(abs(angle) * 13.5);

  if (angle > 0) {
    set_motor_speeds(-0.20, 0.20);
  } else {
    set_motor_speeds(0.20, -0.20);
  }

  delay(delay_duration);
  set_motor_speeds(0, 0);
}

void open_loop_go_forward(float distance) {
  //This function drives the wheels at 0.17m/s speed. thus each milisecond, it travels 0.00017m/ms
  //By using this function, you can go forward ot backward. Just insert negative distance to perform left turn. The distance is given in meters

  //put an upper bound for the distance
  if (distance > 0.25) {
    distance = 0.25;
  } else if (distance < -0.25) {
    distance = -0.25;
  }

  uint16_t delay_duration = uint16_t(abs(distance) / 0.00017);

  if (distance > 0) {  //go forward
    set_motor_speeds(0.19, 0.19);
  } else {
    set_motor_speeds(-0.19, -0.19);
  }

  delay(delay_duration);
  set_motor_speeds(0, 0);
}

void move_forward_until_line_crossing(unsigned long timeout_ms) {
  //TODO: this function should return why it is returned, i.e. line is lost, crossing is found etc.
  float line_position = -99;                 //-99 -> means no line is found.
  static unsigned long line_found_when = 0;  //When the last time a black is detected

  unsigned long start_time = millis();

  while (true) {
    if (millis() - start_time > timeout_ms) break;  //exit the loop after a certain timeout(i.e.~open loop approximated movement time)

    update_black_detections();
    uint8_t number_of_blacks = 0;
    for (uint8_t i = 0; i < 8; i++) {
      if (is_black[i] == 1) number_of_blacks += 1;
    }

    if (number_of_blacks > 4) {  //line crossing is found, STOP
      //HARD BREAK for a short time! Then stop the motors.
      set_motor_speeds(-0.05, -0.05);
      delay(75);
      set_motor_speeds(0.0, 0.0);
      break;
    } else if (number_of_blacks == 0) {  //line is lost, STOP if it is not found for a while using the last line position
      if ((millis() - line_found_when > 750) && line_position != -99) {
        set_motor_speeds(0.0, 0.0);
        line_position = -99;
        break;
      } else if ((millis() - line_found_when < 750) && line_position != -99) {
        //TODO: Should try to find line. Using line_position may be beneficial. Note that it is 'STATIC'
      } else if (line_position == -99) {
        break;
      }
    }

    //=======================================================================================0
    //Keep going forward with feedback.
    if (number_of_blacks > 0) {  // Atleast one sensor detects black.
      line_found_when = millis();
      line_position = 0;
      for (uint8_t i = 0; i < 8; i++) {
        if (is_black[i] == 1) line_position += (i - (3.5));
      }
      line_position = line_position / float(number_of_blacks);  // Ensure that this is a float division
    } else {
      //black is not detected, using previous 'line_position' for a certain duration.
    }

    float BASE_SPEED = 0.20;                 //speed that each motor should go with when the line is centered in m/s
    float del_speed = line_position * 0.03;  // m/s
    float M1_speed = BASE_SPEED - del_speed;
    float M2_speed = BASE_SPEED + del_speed;
    if (M1_speed < 0.14) M1_speed = 0.14;
    if (M2_speed < 0.14) M2_speed = 0.14;

    set_motor_speeds(M1_speed, M2_speed);
  }
}

void move_forward_until_RFID_read() {
  while (true) {
    uint8_t pin_val = digitalRead(RFID_READ);
    if (pin_val == 1) break;
    set_motor_speeds(0.19, 0.19);
  }
  set_motor_speeds(0, 0);

  digitalWrite(buzzerPin, HIGH);  // Turn the buzzer on
  delay(100);                     // Wait for 1 second (1000 milliseconds)
  digitalWrite(buzzerPin, LOW);   // Turn the buzzer off
  delay(100);
}

int move_forward_until_RFID_read_serial() {

  while (Serial.available()) Serial.read();  // empty the buffer

  while (true) {
    set_motor_speeds(0.19, 0.19);
    if (Serial.available() > 0) {
      char c = Serial.read();
      if (c == 's') {
        Serial.println("s is received");
        set_motor_speeds(0, 0);  // stop motor
        break;
      }
    }
  }

  while (true) {
    if (Serial.available() > 0) break;
  }
  // wait to receive command
  int command = Serial.read();
  Serial.println("Command: " + String(command));


  digitalWrite(buzzerPin, HIGH);  // Turn the buzzer on
  delay(100);                     // Wait for 1 second (1000 milliseconds)
  digitalWrite(buzzerPin, LOW);   // Turn the buzzer off
  delay(100);

  return command;
}

void rotate_cw() {
  set_motor_speeds(0.20, -0.20);
}

void rotate_ccw() {
  set_motor_speeds(-0.20, 0.20);
}

void turn_right_closed_loop() {

  while (true) {
    update_black_detections();
    uint8_t number_of_blacks = 0;
    for (uint8_t i = 0; i < 8; i++) {
      if (is_black[i] == 0) {
        number_of_blacks = number_of_blacks + 1;
      }
    }
    if (number_of_blacks != 0) break;
    rotate_cw();
  }

  while (!(is_black[0])) {

    // Serial.println(get_line_pos());
    update_black_detections();
    rotate_cw();
  }

  while (!(is_black[1])) {

    // Serial.println(get_line_pos());
    update_black_detections();
    rotate_cw();
  }

  while (!(is_black[2])) {

    // Serial.println(get_line_pos());
    update_black_detections();
    rotate_cw();
  }

  while (!(is_black[3])) {

    // Serial.println(get_line_pos());
    update_black_detections();
    rotate_cw();
  }
}


void turn_left_closed_loop() {

  while (true) {
    update_black_detections();
    uint8_t number_of_blacks = 0;
    for (uint8_t i = 0; i < 8; i++) {
      if (is_black[i] == 0) {
        number_of_blacks = number_of_blacks + 1;
      }
    }
    if (number_of_blacks != 0) break;
    rotate_ccw();
  }

  while (!(is_black[7])) {

    // Serial.println(get_line_pos());
    update_black_detections();
    rotate_ccw();
  }

  while (!(is_black[6])) {

    // Serial.println(get_line_pos());
    update_black_detections();
    rotate_ccw();
  }

  while (!(is_black[5])) {

    // Serial.println(get_line_pos());
    update_black_detections();
    rotate_ccw();
  }

  while (!(is_black[4])) {

    // Serial.println(get_line_pos());
    update_black_detections();
    rotate_ccw();
  }
}

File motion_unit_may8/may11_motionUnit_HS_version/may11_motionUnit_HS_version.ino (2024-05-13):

uint8_t analog_pins[8] = { A0, A1, A2, A3, A4, A5, A6, A7 };  // A0-> 2 (left) A5->7 (right)Define the analog input pins, 4 D1, 5 D7
#define rightMotor1 D4                                 //right motor 240RPM
#define rightMotor2 D12
#define right_pwm_normalizer D1
#define rightMotorPWM D10
#define leftMotor1 D8  //right motor 320RPM
#define leftMotor2 D7
#define leftMotorPWM D11
#define left_pwm_normalizer 0.9
#define LED_PIN D13
#define ISRESETTED 13
#define RFID_READ D2
#define FOLLOWING_THE_LINE 1
#define AT_CROSS_SECTION 2


float last_position = 0;
uint8_t base_pwm = 90;
int intersection = 0;
uint8_t is_black[8] = { 0, 0, 0, 0, 0, 0, 0, 0};
int stop = 0;
int receivedValue = 0;
int state = 1;


// Function prototype
uint8_t update_black_detections(int black_threshold);
void test_print_is_black_array();
float get_line_pos();
void rotate_cw();
void rotate_ccw();
void move(int line_position);
void drive_right_motor_at(int pwm_val, int update_period_ms, uint8_t delta_pwm_per_period);
void drive_left_motor_at(int pwm_val, int update_period_ms, uint8_t delta_pwm_per_period);
void stop_mu();


/*  digitalWrite(rightMotor1,HIGH);
    digitalWrite(rightMotor2, LOW); right motor forward

    digitalWrite(leftMotor1,LOW);
    digitalWrite(leftMotor2, HIGH); left motor forward
*/
void setup() {
  Serial.begin(9600);
  Serial.println("resetted!!!");
  pinMode(ISRESETTED, OUTPUT);
  digitalWrite(ISRESETTED, HIGH);
  delay(2000);
  digitalWrite(ISRESETTED, LOW);
  pinMode(LED_PIN, OUTPUT);
  pinMode(rightMotor1, OUTPUT);
  pinMode(rightMotor2, OUTPUT);
  pinMode(rightMotorPWM, OUTPUT);
  pinMode(leftMotor1, OUTPUT);
  pinMode(leftMotor2, OUTPUT);
  pinMode(leftMotorPWM, OUTPUT);
  pinMode(RFID_READ, INPUT);


  for (uint8_t i = 0; i < 8; i++) {
    pinMode(analog_pins[i], INPUT);
  }
}

unsigned int threshold = 900;  // Threshold for detecting black
uint8_t indicator = 0;
uint8_t oldData = 0;
uint16_t turn_delay = 1000;
unsigned long oldData_startTime = 0;


void loop() {
  
  update_black_detections(threshold);
  
  // if(check_for_cross_section()){
  //   state = AT_CROSS_SECTION;
  // }
  // else{
  //   state = FOLLOWING_THE_LINE;
  // }

  if(digitalRead(RFID_READ)==1){
    Serial.println("Read an RFID, stopping.1");
    stop_RFID();
    Serial.println("Read an RFID, stopping.");
  }

  unsigned long currentTime = millis();
  if (currentTime - oldData_startTime > 3000){oldData = 0;}
  //Checking if there is any new data from the RFID reader
  if (Serial.available() > 0) { // Check if data is available to read

    uint8_t receivedNum = Serial.read(); // Read the incoming byte
    if (receivedNum != oldData){
    Serial.print("Received: ");
    Serial.println(receivedNum); // Print the received character
    uint8_t x = int(receivedNum) / 16;
    uint8_t y = int(receivedNum) % 16;
    Serial.println(x);
    Serial.println(y);

    Serial.println("An RFID card has been read");
    if(x==1 && y==1){
      Serial.println("Starting rotating CW");
      turn_left();
    }

    if(x==1 && y==2){
      turn_left();
      Serial.println("Starting rotating CW");

    }

    if(x==1 && y==3){
      Serial.println("Starting rotating CW");
      turn_left();
    }

    if(x==2 && y==1){
      turn_left();
      Serial.println("Starting rotating CW");

    }

    if(x==2 && y==2){
      turn_left();
      Serial.println("Starting rotating CW");

    }

    if(x==2 && y==3){
      turn_left();
      Serial.println("Starting rotating CW");

    }

    oldData = receivedNum;
    oldData_startTime = millis();
    }
  }

  // if(state == AT_CROSS_SECTION)
  // {
  //   move_straight_ahead();
  //   //stop_RFID();
  // }
  // else{
  
  float line_position = get_line_pos();  // This will be deleted
  move(line_position);
  
  // }

}



void move(int line_position) {
  if (line_position == -999) {
    // Serial.println("No line is found");

    if (last_position > 0) {
      rotate_cw();
    } else {
      rotate_ccw();
    }

  }
    else if (line_position > 0) {
      int right_pwm = int(base_pwm * right_pwm_normalizer);
      int left_pwm = int((base_pwm + 1.5 * line_position * line_position) * left_pwm_normalizer);
      drive_left_motor_at(left_pwm, 30, 1);
      drive_right_motor_at(right_pwm, 30, 1);
      last_position = line_position;
    }
    else {
      line_position = -line_position;
      int right_pwm = int((base_pwm + 1.5 * line_position * line_position) * right_pwm_normalizer);
      int left_pwm = int(base_pwm * left_pwm_normalizer);
      drive_left_motor_at(left_pwm, 30, 1);
      drive_right_motor_at(right_pwm, 30, 1);
      last_position = -line_position;
    }
  }




  uint8_t update_black_detections(int black_threshold) {
    //uint8_t analog_pins[8] = {A0, A1, A2, A3, A4, A5, A6, A7}; // A0-> 2 (left) A7->7 (right)Define the analog input pins
    //right -> 2, left ->7

    for (uint8_t i = 0; i < 8; i++) {
      int analog_value = analogRead(analog_pins[i]);
      uint8_t digital_val = 0;
      if (analog_value > black_threshold) digital_val = 1;
      is_black[i] = digital_val;
    }
  }
  float get_line_pos() {
    int sensor_coefficients[8] = { 4, 3, 2, 1, -1, -2, -3, -4 };
    float pos_value = 0;
    uint8_t black_counter = 0;

    for (int i = 0; i < 8; i++) {
      if (is_black[i]) {
        pos_value = pos_value + sensor_coefficients[i];
        black_counter = black_counter + 1;
      }
    }

    if (black_counter != 0) {
      pos_value = pos_value / black_counter;
    } else {
      pos_value = -999;
    }
    //no line is found

    return pos_value;
  }

  void test_print_is_black_array() {
    for (uint8_t i = 0; i < 8; i++) {
       Serial.print(String(is_black[i]) + " ");
    }
     Serial.println("");
  }

  void drive_right_motor_at(int pwm_val, int update_period_ms, uint8_t delta_pwm_per_period) {
    static unsigned long last_time_update = 0;
    static uint8_t actual_pwm = 0;
    if (millis() - last_time_update < update_period_ms) return;
    int delta_actual_pwm = pwm_val - actual_pwm;

    if (delta_actual_pwm < -delta_pwm_per_period) {
      delta_actual_pwm = -delta_pwm_per_period;
    } else if (delta_actual_pwm > delta_pwm_per_period) {
      delta_actual_pwm = delta_pwm_per_period;
    }
    actual_pwm = actual_pwm + delta_actual_pwm;

    //------------

    if (actual_pwm < 0) {  //go reverse
      digitalWrite(rightMotor1, HIGH);
      digitalWrite(rightMotor2, LOW);
      analogWrite(rightMotorPWM, actual_pwm);
    } else {
      digitalWrite(rightMotor1, LOW);
      digitalWrite(rightMotor2, HIGH);
      analogWrite(rightMotorPWM, actual_pwm);
    }
  }

  void drive_left_motor_at(int pwm_val, int update_period_ms, uint8_t delta_pwm_per_period) {
    static unsigned long last_time_update = 0;
    static uint8_t actual_pwm = 0;
    if (millis() - last_time_update < update_period_ms) return;
    int delta_actual_pwm = pwm_val - actual_pwm;
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

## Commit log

2023-11-27 motion unit first pwm example
2023-12-02 right motor drive and annoying sound is finished
2023-12-04 IR devices are well understood
2023-12-12 Best case simulation
    When each mu knows where the target is.
2024-02-24 folder structure is reorganized
    [mirror_surface.stl, rotating_body.stl, stand.stl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]
2024-03-04 Robot and Sensor classes are defined
2024-03-04 Ultrasonic sensor is also implemented
2024-04-19 Test on sensor
2024-05-13 Decision Unit distance_matrix fixed. Works WELL.
    [DecisionUnArd_function.ino, DecisionUnArd_main.ino, DecisionUnArd_main_humo.ino]
2024-05-26 Decision wo collision avoidance MU1 & MU2
    [DecisionUnArd_WORKS_GOOD.ino, DecisionUnArd_WORKS_GOOD_MU2.ino, DecisionUnArd_function.ino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]
2024-05-27 Collision Integrated MU1 and MU2
    [DecisionUnArd_WORKS_GOOD.ino, DecisionUnArd_WORKS_GOOD_MU2.ino, DecisionUnArd_function.ino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]
2024-05-29 UI target bug is fixed
    [objects.py]
